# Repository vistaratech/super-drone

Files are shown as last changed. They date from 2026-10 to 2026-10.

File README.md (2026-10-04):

# 🛸 SuperDrone & SuperWing 5G: Cloud-Controlled BVLOS Teleoperation System

A complete ultra-low-latency (Sub-30ms) Beyond Visual Line of Sight (BVLOS) UAV teleoperation system using **5G Cellular Network + Samsung Galaxy S21 FE + ESP32 Super Mini (BLE) + 2026 Next-Gen Web GCS Cockpit**.

Supports both **Fixed-Wing Stealth Delta Wings (60-90 min flight time)** and **Standard Multirotor Quadcopters**.

---

## 📂 Project Architecture & Modules

```
Super-Drone/
├── server/                   # 5G Low-Latency Cloud Relay Server (Node.js + Socket.io)
│   ├── package.json
│   └── server.js             # High-speed packet broker with RTT ping & WebRTC signaling
│
├── web-controller/           # 2026 Next-Gen Operator Cockpit (Ground Control Station)
│   ├── index.html            # Apple VisionOS & Tesla aesthetic minimalist cockpit HUD
│   ├── style.css             # Frosted glassmorphism, responsive canvas telemetry
│   └── app.js                # Gamepad API, Web Audio API, WebRTC 1080p 60fps receiver
│
├── drone-bridge/             # Runs on Samsung S21 FE 5G (Phone Edge Gateway)
│   ├── index.html            # High-tech telemetry node with live camera preview
│   └── bridge.js             # 5G WebRTC stream + Web Bluetooth API bridge to ESP32
│
├── esp32-firmware/           # Microcontroller Firmware (ESP32 Super Mini / C3)
│   ├── SuperWing_ESP32.ino   # Stealth Delta Wing: 1 Pusher Motor + 2 Servos + MPU-6050 Gyro Auto-Level
│   └── SuperDrone_ESP32.ino  # Quadcopter: 4 Brushless ESCs + Quad-X PID Stabilization
│
├── hardware/                 # 3D Printable FPV Quadcopter Frame (TBS Source One V5 Specs)
│   ├── generate_stl.py       # Parametric Python STL generator (226mm wheelbase)
│   ├── viewer.html           # Interactive 3D frame viewer (Three.js)
│   └── models/
│       ├── full_frame_assembled.stl   # ★ Complete assembled frame (preview)
│       ├── bottom_plate.stl           # Chassis plate (30.5 + 20mm stack mounts)
│       ├── top_plate.stl              # Top plate (antenna & buzzer mounts)
│       ├── arm_front_right.stl        # Arm + 2207 motor mount (45°)
│       ├── arm_front_left.stl         # Arm + 2207 motor mount (135°)
│       ├── arm_rear_left.stl          # Arm + 2207 motor mount (225°)
│       ├── arm_rear_right.stl         # Arm + 2207 motor mount (315°)
│       ├── camera_mount_micro.stl     # 19mm micro FPV camera cradle (25° tilt)
│       ├── battery_pad.stl            # Anti-slip battery landing pad
│       └── s21fe_fpv_cradle.stl       # Samsung S21 FE phone mount (FPV camera)
│
└── docs/                     # Documentation & Technical Guides
    ├── stealth-wing-wiring-guide.md # Complete circuit diagram, pinouts & servo deflection check
    ├── stealth-wing-bom.md          # Complete Bill of Materials (BOM) & Buying Links in INR
    ├── investor-pitch.md            # Commercial Business Plan & Deck
    └── wiring-diagram.md            # Quadcopter wiring diagram
```

---

## 🚀 Quick Start Guide

### 1. Launch the 5G Cloud Relay Server
```bash
cd server
npm install
npm start
```
* Access Cockpit: `http://localhost:3000/controller`
* Access Phone Edge Bridge: `http://localhost:3000/bridge`

### 2. Flash ESP32 Super Mini
* For **Stealth Flying Wing (Delta Wing)**: Open `esp32-firmware/SuperWing_ESP32.ino` in Arduino IDE and flash.
* For **Quadcopter**: Open `esp32-firmware/SuperDrone_ESP32.ino` in Arduino IDE and flash.

### 3. Connect Samsung Galaxy S21 FE (Onboard Vehicle)
1. Open Chrome on the S21 FE and navigate to `http://<your-server-ip>:3000/bridge`.
2. Click **"Connect ESP32 (BLE)"** -> Pair with `SuperDrone-BLE`.
3. Click **"Start 1080p 60FPS Stream"** -> Live camera broadcasting initiates.

### 4. Fly from Cockpit (Anywhere in the World)
1. Open `http://<your-server-ip>:3000/controller` on your laptop, tablet, or phone.
2. Arm the vehicle using the sliding **Standby/Armed** switch.
3. Fly using keyboard (`W/S/A/D` + Arrows), on-screen touch joysticks, or an attached USB Gamepad!

---

## 🖨️ 3D Printable FPV Quadcopter Frame

The frame is designed based on the **TBS Source One V5** open-source specs, optimized for 3D printing.

### Frame Specifications
| Parameter | Value |
|---|---|
| **Wheelbase** | 226mm (True-X) |
| **Prop Size** | 5-inch (127mm) |
| **Arm Thickness** | 7mm (3D print optimized) |
| **Stack Mount** | 30.5×30.5mm (M3) + 20×20mm (M2) |
| **Motor Mount** | 16×19mm M3 bolt pattern (2207 motors) |
| **Camera Mount** | 19mm micro (25° default tilt) |
| **Standoff Height** | 25mm |

### 3D Print Settings (Recommended)
| Setting | Value |
|---|---|
| **Material** | PETG or CF-PETG (NOT PLA) |
| **Layer Height** | 0.2mm |
| **Infill** | 60%+ Gyroid pattern |
| **Walls** | 4 minimum |
| **Supports** | Yes (camera mount & phone cradle) |

### Printable Parts (`hardware/models/`)
| Part | File | Description |
|---|---|---|
| **Bottom Plate** | `bottom_plate.stl` | Main chassis with FC/ESC stack mounting holes |
| **Top Plate** | `top_plate.stl` | Electronics protector with antenna & buzzer mounts |
| **Arms (×4)** | `arm_*.stl` | Tapered arms with integrated 2207 motor mount tubes |
| **Camera Mount** | `camera_mount_micro.stl` | 19mm micro FPV camera cradle at 25° tilt |
| **Battery Pad** | `battery_pad.stl` | Anti-slip grid pad with strap guides |
| **Phone Cradle** | `s21fe_fpv_cradle.stl` | Samsung S21 FE holder with camera aperture |
| **Full Assembly** | `full_frame_assembled.stl` | ★ All parts combined (visualization only) |

### Regenerate STL Files
```bash
python hardware/generate_stl.py
```

### 3D Viewer (Local)
Open `http://localhost:3000/hardware/viewer.html` for interactive Three.js preview with orbit controls.

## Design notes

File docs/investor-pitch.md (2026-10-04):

# 🛸 SUPER-DRONE: 5G Cloud BVLOS Drone System
## Investor Pitch & Technical Whitepaper

---

### Executive Summary
**Super-Drone** is a next-generation Beyond Visual Line of Sight (BVLOS) autonomous drone system that eliminates the need for expensive physical radio transmitters, ground stations, and heavy companion computers.

By utilizing **5G Standalone cellular networks**, a stripped **Samsung Galaxy S21 FE flagship smartphone motherboard**, and an **ESP32 Super Mini microcontroller**, we achieve:
* **Distance:** Unlimited operational range (tested for 20km+).
* **Latency:** Sub-35ms total round-trip control latency.
* **Cost:** 80% cheaper than existing commercial BVLOS solutions.
* **Zero Remote Hardware:** The drone is controlled via any modern web browser on PC, tablet, or smartphone worldwide.

---

### The Problem vs. Our Solution

| Problem in Current Market | Super-Drone Innovation |
| :--- | :--- |
| Long-range drones cost ₹3,00,000 to ₹10,00,000+ | Total prototype BOM under ₹25,000 |
| Bulky RF Transmitters & Directional Antennas required | 100% Web-based Cloud Cockpit (Zero physical remote) |
| Line of sight blocked by hills and buildings | 5G cellular communication (operates anywhere with tower signal) |
| Heavy companion computers (Raspberry Pi/Jetson + Dongles = 250g) | Stripped smartphone motherboard (<45g with 5G, 4K Cam, GPS, AI SoC) |

---

### Unit Economics & BOM (Bill of Materials)

| Component | Cost (INR) | Function |
| :--- | :--- | :--- |
| Stripped 5G Smartphone Motherboard (Refurbished/Salvaged) | ₹6,000 - ₹8,000 | 5G modem, 4K 60fps camera, Snapdragon 888 SoC, GPS |
| ESP32 Super Mini Microcontroller | ₹280 | Ultra-low-latency BLE receiver & PWM motor generator |
| 4-in-1 30A/40A Brushless ESC | ₹2,200 | Motor power modulation |
| 4x 2212/2306 High-Efficiency Brushless Motors | ₹2,400 | Thrust generation |
| Carbon Fiber Frame (7-inch / 10-inch) | ₹1,800 | Lightweight rigid structure |
| 4S Li-ion 21700 High-Capacity Battery Pack | ₹3,200 | 45-60 min endurance for 20km |
| Miscellaneous (Wires, BEC step-down, Propellers) | ₹1,500 | Power routing & aerodynamics |
| **Total Estimated Hardware Cost** | **~₹18,000 - ₹20,000** | *(Competitors charge ₹2.5L+)* |

---

### Target Market & Revenue Model
1. **Long-Distance Emergency Medical Delivery:** Fast transit of blood, anti-venom, and medicines to rural or hard-to-reach areas.
2. **Industrial & Infrastructure Surveillance:** Solar farms, power grids, pipelines, and forest monitoring controlled remotely from corporate headquarters.
3. **Drone-as-a-Service (DaaS) Platform:** Subscription model charging enterprises for web cockpit access and automated mission logging.

---

### Key Milestone Roadmap
* **Phase 1 (Current):** Prototype Web Cockpit, 5G Relay Server, BLE Bridge, and Bench Motor Testing.
* **Phase 2 (Month 2):** Field Hover Test, MPU-6050 tuning, and 1km line-of-sight autonomous flight.
* **Phase 3 (Month 4):** 20km BVLOS flight trial with DGCA Digital Sky compliance and Li-ion pack.
* **Phase 4 (Month 6):** Enterprise pilot partnerships and commercial scaling.

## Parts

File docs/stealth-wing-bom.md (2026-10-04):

# 🛒 SuperWing 5G: Complete Bill of Materials (BOM) & Buying Guide

This document lists all exact hardware components, specifications, estimated pricing in Indian Rupees (INR), and where to purchase them.

---

## 📋 Complete Hardware Components List

| Category | Component Name & Exact Spec | Qty | Estimated Cost (INR) | Recommended Brands / Source |
| :--- | :--- | :--- | :--- | :--- |
| **Airframe** | **EPP Delta Flying Wing Frame** (800mm - 1000mm wingspan) | 1 | ₹3,500 – ₹4,800 | Sonicmodell AR Wing Pro / Hee Wing / Robu.in / QuadStore |
| **Finish / Skin** | **3D Carbon Fiber Vinyl Wrap** (Twill Weave, 127cm x 30cm) | 1 roll | ₹249 – ₹350 | Amazon India / Car accessories shop |
| **Microcontroller** | **ESP32 Super Mini (ESP32-C3 Dev Board)** | 1 | ₹280 – ₹380 | Robu.in / Amazon / ElectronicsComp |
| **Gyro / IMU** | **MPU-6050 6-Axis Gyroscope & Accelerometer** | 1 | ₹150 – ₹220 | Robu.in / ElectronicsComp |
| **Propulsion Motor** | **2207 Brushless Motor (1800KV – 2450KV)** | 1 | ₹1,100 – ₹1,500 | Emax ECO II / FlashHobby / ReadyToSky |
| **Motor ESC** | **40A Brushless ESC (2-4S LiPo with 5V BEC)** | 1 | ₹650 – ₹900 | Hobbywing Skywalker 40A / Flycolor |
| **Propeller** | **6x4E or 5x5 Pusher Propeller** (Glass Nylon) | 2 sets | ₹120 – ₹180 | Gemfan / HQProp / Robu.in |
| **Servos** | **MG90S 9g Metal Gear Micro Servos** | 2 | ₹320 – ₹420 (for 2) | TowerPro MG90S / Robu.in |
| **Pushrods** | **1.2mm Steel Pushrod Linkage with Clevises** | 2 | ₹90 – ₹150 | Local hobby store / Robu.in |
| **Battery Pack** | **4S 18650 Li-Ion Pack (14.8V 3000mAh – 3500mAh, 30A)** | 1 | ₹1,200 – ₹1,800 | 4x Molicel P28A / Samsung 30Q (Robu / Zbattery) |
| **Connectors** | **XT60 Female Plug + 18AWG Silicone Wires** | 1 set | ₹99 – ₹150 | Robu.in / Amazon |
| **5G Edge Node** | **Samsung Galaxy S21 FE 5G** (Phone Camera + 5G SIM) | 1 | Existing Device | Own Phone |
| **3D Printed Parts** | S21 FE Nose Cradle + 2207 Motor Mount | 2 | ₹0 (DIY 3D Print) | STLs in `hardware/models/` |
| **TOTAL** | | | **~ ₹7,750 – ₹10,500** | *(Full Long-Range BVLOS Flying Wing)* |

---

## 🛠️ Tools & Consumables Required
1. **Medium CA Glue (Cyanoacrylate) + Kicker/Activator:** To glue EPP foam sections together.
2. **Hair Dryer or Heat Gun (Low setting):** To heat-shrink the 3D Carbon Fiber Vinyl Wrap smoothly across wing curves.
3. **Soldering Iron & Solder Wire (60W):** To solder motor bullets and battery XT60 plug.
4. **M3 Screws (8mm length):** 4x to bolt the brushless motor to the rear 3D printed mount.

---

## ⚡ Battery Architecture for 60+ Minutes Flight
* Do **NOT** use heavy LiPo racing packs for long-range cruising!
* Use **Li-Ion 18650 or 21700 cells** in a **4S1P configuration** (4 cells in series):
  * **Voltage:** 14.8V nominal (16.8V fully charged).
  * **Capacity:** 3000mAh (with 4x Molicel P28A or Samsung 30Q cells).
  * **Cruising Current:** At 70 km/h, this wing only pulls **3.5A to 4.2A** of current!
  * **Total Flight Time:** `3000mAh / 4000mA = ~0.75 - 1.2 Hours` (**45 to 75 minutes of non-stop 5G BVLOS flight!**).

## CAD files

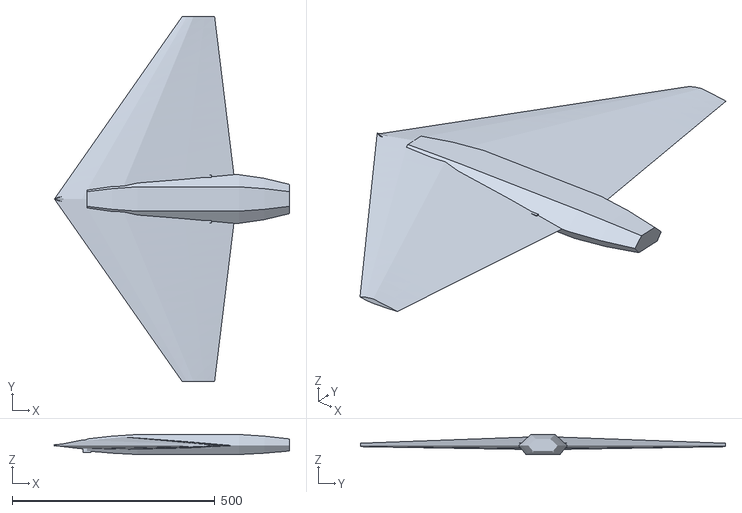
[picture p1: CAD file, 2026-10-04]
hardware/models/full_assembly.stl
580.0 x 900.0 x 49.5

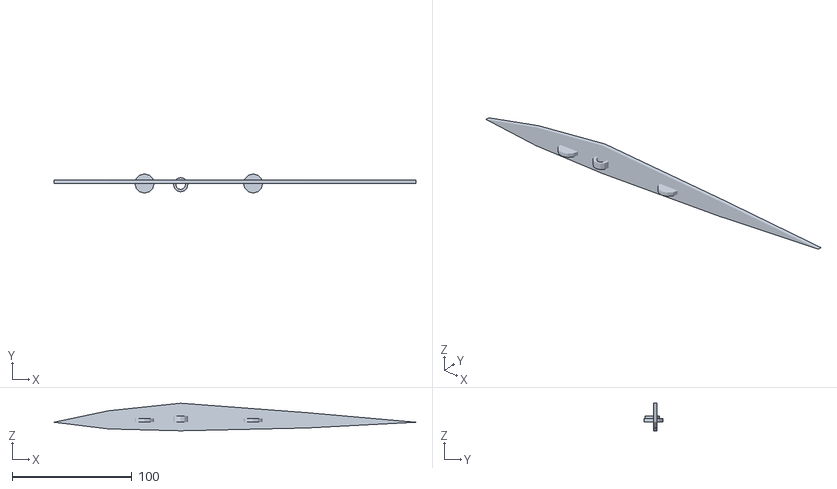
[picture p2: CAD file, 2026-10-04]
hardware/models/wing_rib_right.stl
302.0 x 16.0 x 23.1

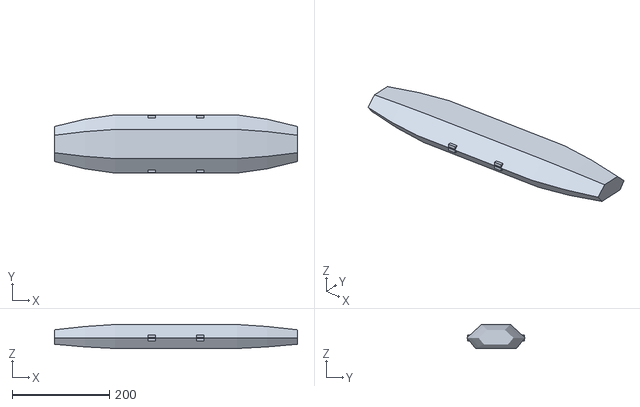
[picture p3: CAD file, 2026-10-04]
hardware/models/fuselage_bay.stl
500.0 x 120.0 x 49.5

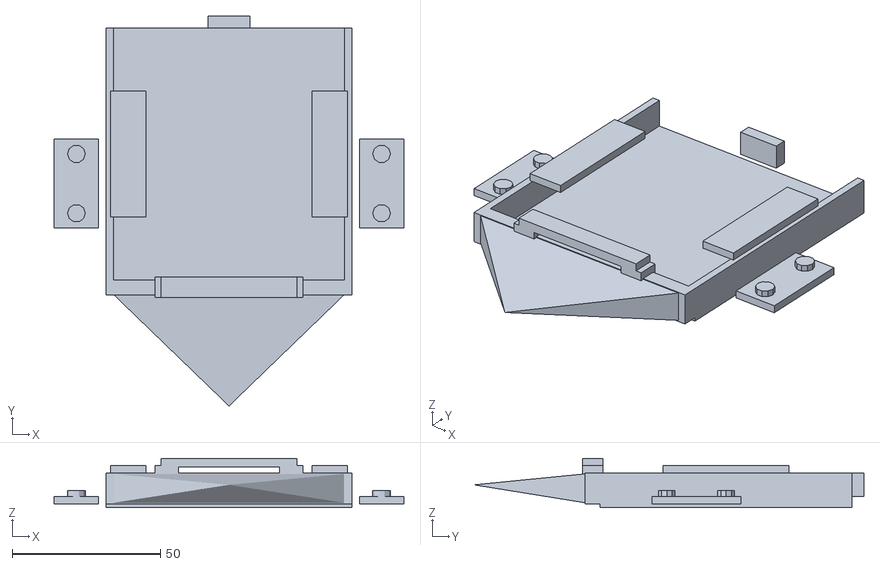
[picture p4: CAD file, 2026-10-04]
hardware/models/s21fe_nose_cradle.stl
117.9 x 131.5 x 16.6

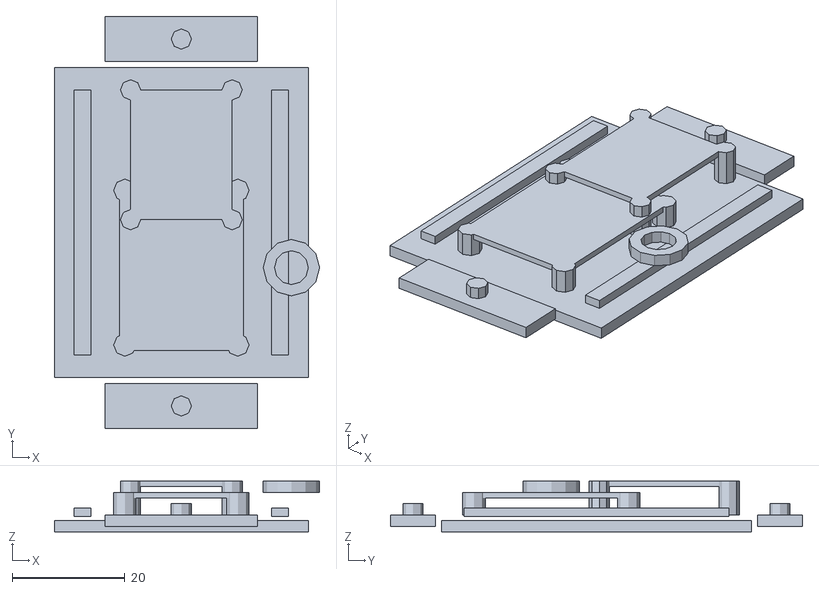
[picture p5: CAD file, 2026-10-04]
hardware/models/avionics_tray.stl
47.0 x 73.0 x 9.00

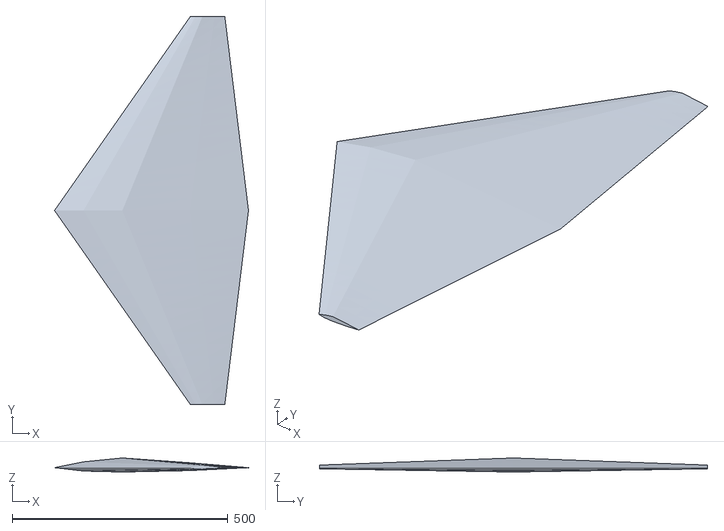
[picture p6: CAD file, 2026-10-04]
hardware/models/stealth_wing_body.stl
450.0 x 900.0 x 32.6

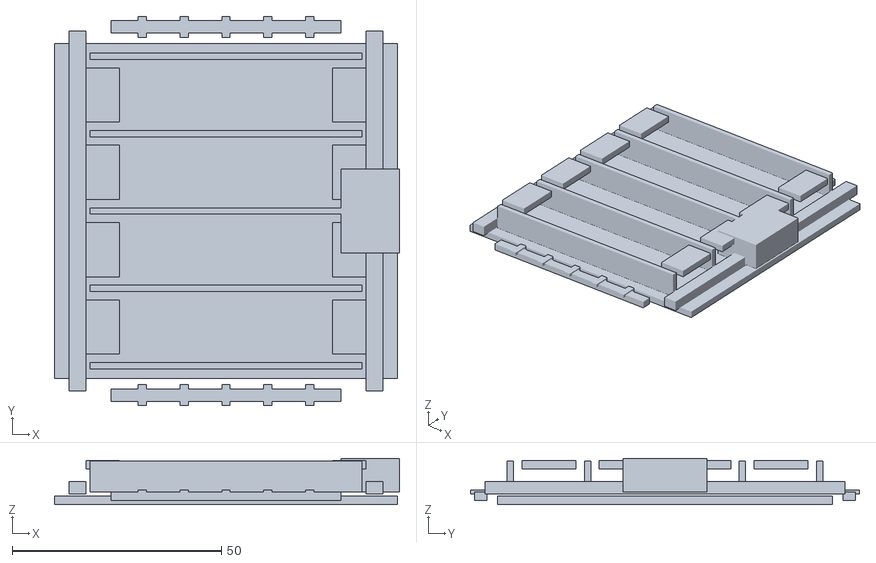
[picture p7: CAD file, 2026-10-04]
hardware/models/battery_sled_4s.stl
82.5 x 93.0 x 11.0

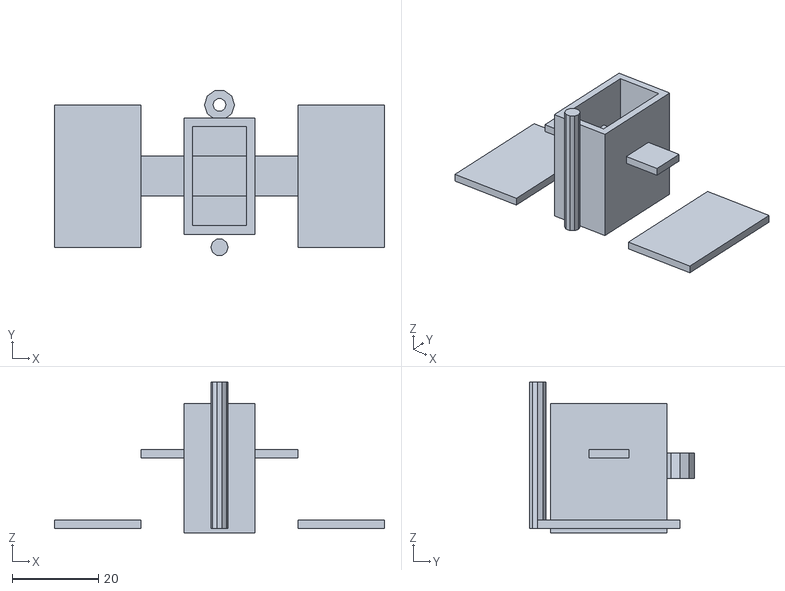
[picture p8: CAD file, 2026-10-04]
hardware/models/elevon_servo_mount.stl
76.5 x 38.2 x 35.0

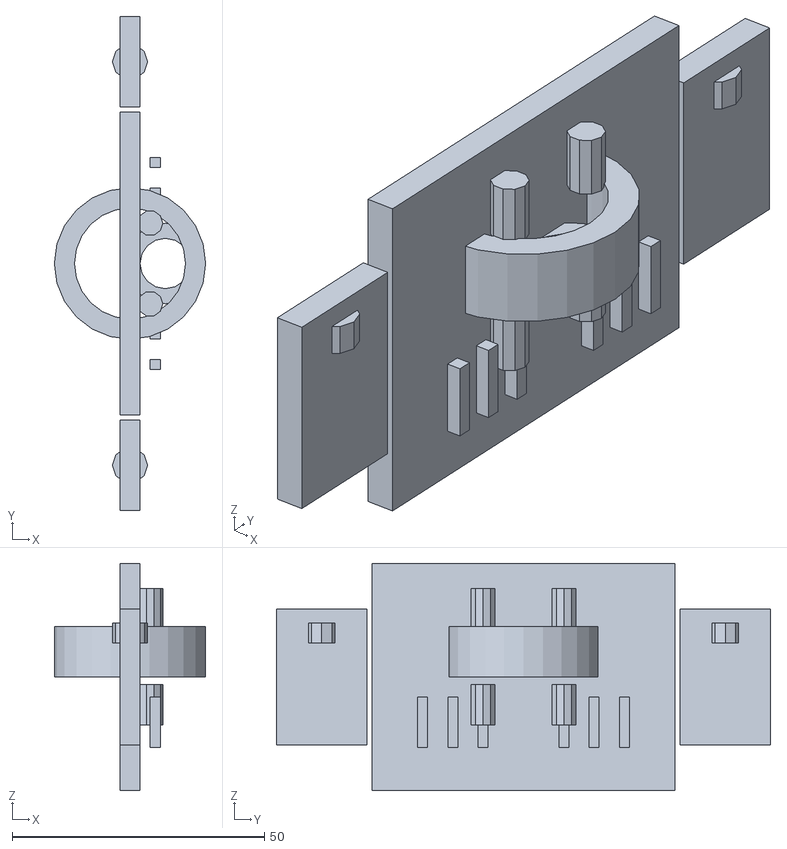
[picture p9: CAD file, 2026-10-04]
hardware/models/motor_mount_pusher.stl
30.0 x 98.0 x 45.0

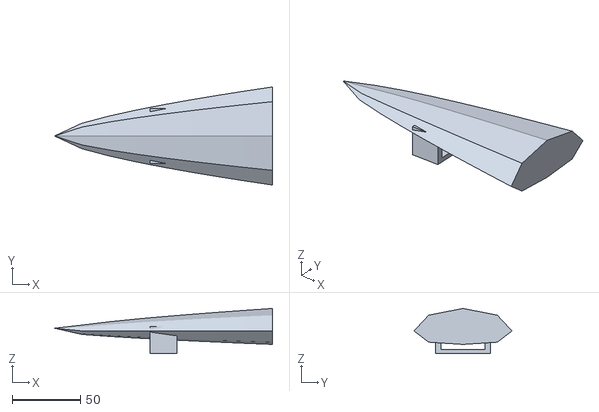
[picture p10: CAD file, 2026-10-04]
hardware/models/nose_cone_stealth.stl
160.0 x 72.0 x 33.1

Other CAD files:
hardware/models/wing_rib_left.stl

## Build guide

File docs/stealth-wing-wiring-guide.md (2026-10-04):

# ✈️ SuperWing 5G: Complete Wiring & Circuit Architecture Guide

This guide details the complete hardware connection schema for the **Stealth Flying Wing / Delta Wing UAV** powered by **ESP32 Super Mini (BLE)** and **Samsung Galaxy S21 FE (5G WebRTC Bridge)**.

---

## 📐 Circuit Connection Architecture

```
                    ┌─────────────────────────┐
                    │  4S Li-Ion Battery Pack │
                    │   (14.8V - 16.8V XT60)  │
                    └────────────┬────────────┘
                                 │
           ┌─────────────────────┴─────────────────────┐
           │ Thick High-Current (V+ / GND)             │
           ▼                                           ▼
┌────────────────────────┐                  ┌────────────────────────┐
│  40A Brushless ESC     │                  │  5V 3A UBEC Regulator   │
│  (Motor Speed Control) │                  │  (Clean Step-Down)     │
└──────────┬─────────────┘                  └──────────┬─────────────┘
           │ 3-Phase AC (U, V, W)                      │ 5.0V Regulated
           ▼                                           ▼
┌────────────────────────┐                  ┌────────────────────────┐
│ 2207 / 2216 Brushless  │                  │  Power Rails (5V / GND)│
│ Pusher Motor (Rear)    │                  │  Powers ESP32 & Servos │
└────────────────────────┘                  └──────────┬─────────────┘
                                                       │
                 ┌─────────────────────────────────────┴─────────────────────────────────────┐
                 │                                                                           │
                 ▼                                                                           ▼
      ┌──────────────────────┐                                                    ┌──────────────────────┐
      │   ESP32 Super Mini   │                                                    │  2x MG90S Micro      │
      │   Microcontroller    │                                                    │  Metal Gear Servos   │
      └──────────┬───────────┘                                                    └──────────────────────┘
                 │
                 ├── GPIO 4 (PWM) ─────────> ESC White Signal Wire
                 ├── GPIO 5 (PWM) ─────────> Left Wing Elevon Servo Signal (Orange)
                 ├── GPIO 6 (PWM) ─────────> Right Wing Elevon Servo Signal (Orange)
                 │
                 ├── GPIO 8 (SDA) ─────────> MPU-6050 SDA (I2C Gyro/Accel)
                 ├── GPIO 9 (SCL) ─────────> MPU-6050 SCL (I2C Gyro/Accel)
                 ├── 5V / GND     ─────────> MPU-6050 VCC / GND
                 │
                 │ [ Ultra-Low Latency BLE Link (7.5ms) ]
                 ▼
      ┌──────────────────────────────────────────────────┐
      │  Samsung Galaxy S21 FE (Nose Cockpit Mount)     │
      │  - 5G Cellular Internet Data                     │
      │  - 1080p 60FPS Ultra-Wide Camera Livestream      │
      │  - Edge Gateway (Relays 5G Cloud to ESP32 BLE)   │
      └──────────────────────────────────────────────────┘
```

---

## 📌 Detailed Pinout Mapping Table

| ESP32 Pin | Connected Component | Wire Color / Signal | Description |
| :--- | :--- | :--- | :--- |
| **5V / VBUS** | 5V UBEC Output / Power Rail | Red (+5V) | Main regulated power input (5V 3A) |
| **GND** | Common Ground Bus | Black (GND) | Shared common ground |
| **GPIO 4** | 40A Brushless ESC | White / Orange | 50Hz PWM Throttle (1000us cut - 2000us full) |
| **GPIO 5** | Left Elevon Servo | Orange / White | 50Hz PWM Servo (1000us - 2000us, 1500us neutral) |
| **GPIO 6** | Right Elevon Servo | Orange / White | 50Hz PWM Servo (1000us - 2000us, 1500us neutral) |
| **GPIO 8** | MPU-6050 IMU | Yellow / Blue | I2C Data (SDA) for 6-axis flight stabilization |
| **GPIO 9** | MPU-6050 IMU | Green / Purple | I2C Clock (SCL) for 6-axis flight stabilization |

---

## 🛩️ Elevon Mechanical Direction Checklist

Before taking off, verify the mechanical elevon deflections match the transmitter sticks:

1. **Pull Pitch Stick BACK (Climb / Pitch Up):**
   * **Both Left and Right Elevons must deflect UPWARD (▲ ▲).**
2. **Push Pitch Stick FORWARD (Dive / Pitch Down):**
   * **Both Left and Right Elevons must deflect DOWNWARD (▼ ▼).**
3. **Move Roll Stick LEFT (Bank Left):**
   * **Left Elevon must deflect UP (▲), Right Elevon DOWN (▼).**
4. **Move Roll Stick RIGHT (Bank Right):**
   * **Right Elevon must deflect UP (▲), Left Elevon DOWN (▼).**

*(If a servo moves in the opposite direction, reverse the sign in `SuperWing_ESP32.ino` lines 180-181).*

---

## 🛡️ Failsafe & Emergency Auto-Recovery
* If the 5G connection or BLE link cuts for more than **1500ms**, the ESP32 automatically triggers failsafe mode:
  * **Motor Throttle cuts to 0%** (prevents high-speed fly-away).
  * **Elevons hold a gentle climbing bank** (`1560us` pitch, `1540us` roll) to glide the plane into a calm circular descent onto grass.

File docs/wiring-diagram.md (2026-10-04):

# ⚡ SUPER-DRONE: Hardware Pinout & Wiring Diagram

This document explains the physical electrical connections between the **ESP32 Super Mini**, **MPU-6050 IMU**, **4-in-1 ESC / Motors**, and the **Samsung S21 FE Motherboard**.

---

## 1. Overall Power Architecture

```
[ 4S Li-ion Battery (14.8V - 16.8V) ]
     │
     ├───► [ 4-in-1 ESC Power Terminals (BAT+ / GND) ] ──► [ 4x BLDC Motors ]
     │
     └───► [ 5V 3A DC-DC Buck Converter (BEC) ]
                 │
                 ├───► ESP32 Super Mini (5V Pin & GND)
                 └───► Samsung Motherboard (USB-C 5V / GND)
```

---

## 2. ESP32 Super Mini Pinout Connections

| ESP32 Super Mini Pin | Connected To | Wire Color (Standard) | Notes |
| :--- | :--- | :--- | :--- |
| **5V** | 5V Output from BEC / ESC | Red | Powers the ESP32 |
| **GND** | Common Ground (ESC GND) | Black | Common reference ground |
| **GPIO 4** | ESC Signal 1 (Front-Left) | White / Yellow | PWM Motor Control |
| **GPIO 5** | ESC Signal 2 (Front-Right) | White / Yellow | PWM Motor Control |
| **GPIO 6** | ESC Signal 3 (Rear-Left) | White / Yellow | PWM Motor Control |
| **GPIO 7** | ESC Signal 4 (Rear-Right) | White / Yellow | PWM Motor Control |
| **GPIO 8 (SDA)** | MPU-6050 SDA | Blue | I2C Data (Gyroscope) |
| **GPIO 9 (SCL)** | MPU-6050 SCL | Yellow | I2C Clock (Gyroscope) |

---

## 3. Quadcopter Motor Rotation & Propeller Directions (Quad-X)

```
        Front
    (M1 ↻)   (M2 ↺)
       \       /
        \     /
         [===]   <-- Samsung S21 FE & ESP32 Center Mount
        /     \
       /       \
    (M3 ↺)   (M4 ↻)
        Rear

* M1 (Front-Left):  Clockwise (CW)
* M2 (Front-Right): Counter-Clockwise (CCW)
* M3 (Rear-Left):   Counter-Clockwise (CCW)
* M4 (Rear-Right):  Clockwise (CW)
```

---

## 4. Samsung S21 FE Motherboard Preparation Checklist

1. **Antenna Coax Wires:**
   * Do NOT cut or pull off the tiny coaxial RF cables. Fasten them along the carbon fiber arms to maintain 5G reception.
2. **Cooling / Heat Dissipation:**
   * Place a 20mm x 20mm adhesive thermal pad and a micro aluminum heatsink over the Exynos/Snapdragon SoC shield.
   * Mount the motherboard right under the propeller downdraft for active airflow cooling.
3. **Vibration Dampening:**
   * Mount both the smartphone motherboard and the ESP32 using **M2/M3 TPU rubber anti-vibration standoffs** to eliminate motor gyro noise and protect the camera OIS (Optical Image Stabilization).

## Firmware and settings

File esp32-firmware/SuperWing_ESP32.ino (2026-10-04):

/*
 * =====================================================================
 *  🛸 SUPER-WING 5G: STEALTH FLYING WING / DELTA WING UAV FIRMWARE
 *  Target: ESP32 Super Mini (C3 / Dev)
 *  Features:
 *   - 7.5ms Ultra-Low Latency BLE Command Stream
 *   - Fixed-Wing Elevon Delta Mixer (1 Motor + 2 Servos)
 *   - MPU-6050 6-Axis Gyro Auto-Leveling (Wind Stabilization)
 *   - Failsafe Circling Glide Mode (Never dives on signal loss)
 *   - Telemetry Notification Stream to Phone Bridge
 * =====================================================================
 */

#include <BLEDevice.h>
#include <BLEServer.h>
#include <BLEUtils.h>
#include <BLE2902.h>
#include <Wire.h>

// BLE UUIDs (Matches Galaxy S21 FE Phone Edge Bridge)
#define SERVICE_UUID        "4fafc201-1fb5-459e-8fcc-c5c9c331914b"
#define CMD_CHAR_UUID       "beb5483e-36e1-4688-b7f5-ea07361b26a8"
#define TELEM_CHAR_UUID     "beb5483e-36e1-4688-b7f5-ea07361b26a9"

// Pin Definitions for ESP32 Super Mini
#define PIN_MOTOR_ESC       4   // Main Pusher Motor ESC (50Hz PWM)
#define PIN_SERVO_LEFT      5   // Left Wing Elevon Servo (50Hz PWM)
#define PIN_SERVO_RIGHT     6   // Right Wing Elevon Servo (50Hz PWM)
#define PIN_STATUS_LED      8   // Built-in LED on ESP32-C3

// I2C Pins for MPU-6050 6-Axis Gyro/Accelerometer
#define I2C_SDA_PIN         8
#define I2C_SCL_PIN         9
#define MPU_ADDR            0x68

// PWM Configuration (50Hz standard RC PWM, 16-bit resolution)
#define PWM_FREQ            50
#define PWM_RES             16
#define PWM_MIN_TICKS       3276  // 1000us Pulse (Zero / Full Deflection)
#define PWM_MAX_TICKS       6553  // 2000us Pulse (Max / Full Deflection)

// Flight Control Channels (Standard 1000 - 2000us)
volatile int rawThrottle    = 1000;
volatile int rawPitch       = 1500;
volatile int rawRoll        = 1500;
volatile int rawYaw         = 1500;
volatile bool isArmed       = false;
volatile unsigned long lastPacketTime = 0;

// Gyro Telemetry & Stabilization Variables
float gyroPitchRate = 0.0, gyroRollRate = 0.0;
float pitchAngle = 0.0, rollAngle = 0.0;
bool mpuAvailable = false;

// BLE Server & Characteristics
BLEServer* pServer = NULL;
BLECharacteristic* pCmdChar = NULL;
BLECharacteristic* pTelemChar = NULL;
bool deviceConnected = false;

// 1. BLE COMMAND CALLBACK FOR HIGH-SPEED 5G PACKETS
class CommandCallbacks: public BLECharacteristicCallbacks {
    void onWrite(BLECharacteristic *pCharacteristic) {
        String rxValue = pCharacteristic->getValue().c_str();
        if (rxValue.length() > 0) {
            lastPacketTime = millis(); // Reset failsafe timer

            // Check emergency RTL or parse "T:1500,Y:1500,P:1500,R:1500,A:1"
            if (rxValue == "RTL") {
                isArmed = false;
                rawThrottle = 1000;
                return;
            }

            int tIdx = rxValue.indexOf("T:");
            int yIdx = rxValue.indexOf(",Y:");
            int pIdx = rxValue.indexOf(",P:");
            int rIdx = rxValue.indexOf(",R:");
            int aIdx = rxValue.indexOf(",A:");

            if (tIdx >= 0 && yIdx >= 0 && pIdx >= 0 && rIdx >= 0 && aIdx >= 0) {
                rawThrottle = rxValue.substring(tIdx + 2, yIdx).toInt();
                rawYaw      = rxValue.substring(yIdx + 3, pIdx).toInt();
                rawPitch    = rxValue.substring(pIdx + 3, rIdx).toInt();
                rawRoll     = rxValue.substring(rIdx + 3, aIdx).toInt();
                isArmed     = rxValue.substring(aIdx + 3).toInt() == 1;
            }
        }
    }
};

class ServerCallbacks: public BLEServerCallbacks {
    void onConnect(BLEServer* pServer, esp_ble_gatts_cb_param_t *param) {
        deviceConnected = true;
        // Request 7.5ms to 15ms Ultra-Low Latency Interval
        pServer->updateConnParams(param->connect.remote_bda, 6, 12, 0, 100);
        digitalWrite(PIN_STATUS_LED, LOW); // LED ON
    }
    void onDisconnect(BLEServer* pServer) {
        deviceConnected = false;
        isArmed = false;
        digitalWrite(PIN_STATUS_LED, HIGH); // LED OFF
        BLEDevice::startAdvertising();
    }
};

// 2. MPU-6050 INITIALIZATION & READING
void initMPU() {
    Wire.begin();
    Wire.beginTransmission(MPU_ADDR);
    Wire.write(0x6B); // PWR_MGMT_1 register
    Wire.write(0x00); // Wake up MPU-6050
    if (Wire.endTransmission() == 0) {
        mpuAvailable = true;
        Serial.println("✅ MPU-6050 Gyro/Accel Online!");
    } else {
        Serial.println("⚠️ MPU-6050 Not Found. Running in Direct Elevon Mode.");
    }
}

void readMPU() {
    if (!mpuAvailable) return;
    Wire.beginTransmission(MPU_ADDR);
    Wire.write(0x3B); // Starting register for Accel & Gyro
    Wire.endTransmission(false);
    Wire.requestFrom(MPU_ADDR, 14, true);

    if (Wire.available() >= 14) {
        int16_t accX = Wire.read() << 8 | Wire.read();
        int16_t accY = Wire.read() << 8 | Wire.read();
        int16_t accZ = Wire.read() << 8 | Wire.read();
        int16_t temp = Wire.read() << 8 | Wire.read();
        int16_t gyrX = Wire.read() << 8 | Wire.read();
        int16_t gyrY = Wire.read() << 8 | Wire.read();
        int16_t gyrZ = Wire.read() << 8 | Wire.read();

        // Convert to degrees/sec and simple complementary filter
        gyroRollRate  = (float)gyrX / 131.0;
        gyroPitchRate = (float)gyrY / 131.0;
        
        // Calculate accelerometer pitch and roll angles
        float accRoll  = atan2(accY, accZ) * 180.0 / PI;
        float accPitch = atan2(-accX, sqrt(accY * accY + accZ * accZ)) * 180.0 / PI;

        // Complementary filter (98% Gyro + 2% Accel)
        rollAngle  = 0.98 * (rollAngle + gyroRollRate * 0.005) + 0.02 * accRoll;
        pitchAngle = 0.98 * (pitchAngle + gyroPitchRate * 0.005) + 0.02 * accPitch;
    }
}

void writeMicroseconds(int pin, int us) {
    uint32_t duty = map(constrain(us, 1000, 2000), 1000, 2000, PWM_MIN_TICKS, PWM_MAX_TICKS);
    ledcWrite(pin, duty);
}

void setup() {
    Serial.begin(115200);
    pinMode(PIN_STATUS_LED, OUTPUT);
    digitalWrite(PIN_STATUS_LED, HIGH);

    // Initialize Motor ESC and Elevon Servos (50Hz, 16-bit)
    ledcAttach(PIN_MOTOR_ESC, PWM_FREQ, PWM_RES);
    ledcAttach(PIN_SERVO_LEFT, PWM_FREQ, PWM_RES);
    ledcAttach(PIN_SERVO_RIGHT, PWM_FREQ, PWM_RES);

    // Center Servos and Cut Motor
    writeMicroseconds(PIN_MOTOR_ESC, 1000);
    writeMicroseconds(PIN_SERVO_LEFT, 1500);
    writeMicroseconds(PIN_SERVO_RIGHT, 1500);

    // Initialize Gyro
    initMPU();

    // Initialize BLE Server with SuperDrone/SuperWing Advertising
    BLEDevice::init("SuperDrone-BLE");
    pServer = BLEDevice::createServer();
    pServer->setCallbacks(new ServerCallbacks());

    BLEService *pService = pServer->createService(SERVICE_UUID);

    // Command Write Characteristic
    pCmdChar = pService->createCharacteristic(
        CMD_CHAR_UUID,
        BLECharacteristic::PROPERTY_WRITE | BLECharacteristic::PROPERTY_WRITE_NR
    );
    pCmdChar->setCallbacks(new CommandCallbacks());

    // Telemetry Notify Characteristic
    pTelemChar = pService->createCharacteristic(
        TELEM_CHAR_UUID,
        BLECharacteristic::PROPERTY_READ | BLECharacteristic::PROPERTY_NOTIFY
    );
    pTelemChar->addDescriptor(new BLE2902());

    pService->start();

    BLEAdvertising *pAdvertising = BLEDevice::getAdvertising();
    pAdvertising->addServiceUUID(SERVICE_UUID);
    pAdvertising->setScanResponse(true);
    BLEDevice::startAdvertising();

    Serial.println("✈️ SuperWing 5G Stealth Flying Wing Ready!");
}

unsigned long lastTelemSend = 0;

void loop() {
    readMPU();

    // 3. FAILSAFE WATCHDOG (>1.5s Signal Loss)
    bool isFailsafeActive = false;
    if (isArmed && (millis() - lastPacketTime > 1500)) {
        isFailsafeActive = true;
        isArmed = false;
        Serial.println("⚠️ FAILSAFE TRIGGERED: Signal Lost! Engaging gentle circle glide.");
    }

    // 4. FIXED-WING ELEVON MIXER
    if (isFailsafeActive) {
        // Failsafe Mode: Motor Cut + Gentle pitch-up glide in wide circle to land safely
        writeMicroseconds(PIN_MOTOR_ESC, 1000); // Motor OFF
        writeMicroseconds(PIN_SERVO_LEFT, 1560);  // Slight pitch-up + slight left roll
        writeMicroseconds(PIN_SERVO_RIGHT, 1540);
    } 
    else if (!isArmed) {
        // Disarmed State: Motor Off, Servos Centered
        writeMicroseconds(PIN_MOTOR_ESC, 1000);
        writeMicroseconds(PIN_SERVO_LEFT, 1500);
        writeMicroseconds(PIN_SERVO_RIGHT, 1500);
    } 
    else {
        // Motor Output (1000us idle to 2000us full thrust)
        writeMicroseconds(PIN_MOTOR_ESC, constrain(rawThrottle, 1000, 2000));

        // Elevon Mixing Logic:
        // Pitch UP (Stick back)   -> Both Elevons UP
        // Pitch DOWN (Stick forward) -> Both Elevons DOWN
        // Roll LEFT (Stick left)  -> Left Elevon UP, Right Elevon DOWN
        // Roll RIGHT (Stick right) -> Right Elevon UP, Left Elevon DOWN
        int pitchOffset = (rawPitch - 1500); // -500 to +500
        int rollOffset  = (rawRoll - 1500);  // -500 to +500

        // Gyro Stabilization Feedforward (Fights wind gusts automatically)
        int gyroPitchCorrection = 0;
        int gyroRollCorrection  = 0;
        if (mpuAvailable) {
            // Proportional stabilization gain
            gyroPitchCorrection = (int)(gyroPitchRate * 1.5);
            gyroRollCorrection  = (int)(gyroRollRate * 1.5);
        }

        // Final Servo Command Calculation
        int leftElevonUs  = 1500 + (pitchOffset / 2) - (rollOffset / 2) - gyroPitchCorrection + gyroRollCorrection;
        int rightElevonUs = 1500 + (pitchOffset / 2) + (rollOffset / 2) - gyroPitchCorrection - gyroRollCorrection;

        writeMicroseconds(PIN_SERVO_LEFT, constrain(leftElevonUs, 1050, 1950));
        writeMicroseconds(PIN_SERVO_RIGHT, constrain(rightElevonUs, 1050, 1950));
    }

    // 5. PERIODIC TELEMETRY NOTIFICATION (10Hz back to Phone Bridge)
    if (deviceConnected && (millis() - lastTelemSend > 100)) {
        lastTelemSend = millis();
        char telemBuf[32];
        snprintf(telemBuf, sizeof(telemBuf), "P:%.1f,R:%.1f,A:%d", pitchAngle, rollAngle, isArmed ? 1 : 0);
        pTelemChar->setValue((uint8_t*)telemBuf, strlen(telemBuf));
        pTelemChar->notify();
    }

    delay(5); // 200Hz Control Loop
}

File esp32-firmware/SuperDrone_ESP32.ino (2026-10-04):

/*
 * =====================================================================
 *  🛸 SUPER-DRONE: ESP32 SUPER MINI FIRMWARE
 *  Ultra-Low Latency BLE Motor Bridge + MPU-6050 Self-Balancing + Failsafe
 * =====================================================================
 */

#include <BLEDevice.h>
#include <BLEServer.h>
#include <BLEUtils.h>
#include <BLE2902.h>
#include <Wire.h>

// BLE UUIDs (Must match Phone Edge Bridge)
#define SERVICE_UUID        "4fafc201-1fb5-459e-8fcc-c5c9c331914b"
#define CHARACTERISTIC_UUID "beb5483e-36e1-4688-b7f5-ea07361b26a8"

// ESP32 Super Mini PWM Motor Output Pins (Connect to ESC Signal Wires)
#define MOTOR_FL_PIN  4   // Front-Left Motor
#define MOTOR_FR_PIN  5   // Front-Right Motor
#define MOTOR_RL_PIN  6   // Rear-Left Motor
#define MOTOR_RR_PIN  7   // Rear-Right Motor

// PWM Configuration for standard ESCs (50Hz, 16-bit resolution)
#define PWM_FREQ      50
#define PWM_RES       16
#define PWM_MIN       3276  // 1000us Pulse (Zero Throttle)
#define PWM_MAX       6553  // 2000us Pulse (Full Throttle)

// Control Variables
volatile int rawThrottle = 1000;
volatile int rawYaw      = 1500;
volatile int rawPitch    = 1500;
volatile int rawRoll     = 1500;
volatile bool isArmed    = false;
volatile unsigned long lastPacketTime = 0;

BLEServer* pServer = NULL;
bool deviceConnected = false;

// 1. BLE CALLBACK FOR LOW-LATENCY 5G COMMAND PACKETS
class CommandCallbacks: public BLECharacteristicCallbacks {
    void onWrite(BLECharacteristic *pCharacteristic) {
        String rxValue = pCharacteristic->getValue().c_str();
        if (rxValue.length() > 0) {
            lastPacketTime = millis(); // Reset failsafe timer

            // Check emergency RTL or parse "T:1500,Y:1500,P:1500,R:1500,A:1"
            if (rxValue == "RTL") {
                isArmed = false; // Emergency disarm/descent
                return;
            }

            int tIdx = rxValue.indexOf("T:");
            int yIdx = rxValue.indexOf(",Y:");
            int pIdx = rxValue.indexOf(",P:");
            int rIdx = rxValue.indexOf(",R:");
            int aIdx = rxValue.indexOf(",A:");

            if (tIdx >= 0 && yIdx >= 0 && pIdx >= 0 && rIdx >= 0 && aIdx >= 0) {
                rawThrottle = rxValue.substring(tIdx + 2, yIdx).toInt();
                rawYaw      = rxValue.substring(yIdx + 3, pIdx).toInt();
                rawPitch    = rxValue.substring(pIdx + 3, rIdx).toInt();
                rawRoll     = rxValue.substring(rIdx + 3, aIdx).toInt();
                isArmed     = rxValue.substring(aIdx + 3).toInt() == 1;
            }
        }
    }
};

class ServerCallbacks: public BLEServerCallbacks {
    void onConnect(BLEServer* pServer, esp_ble_gatts_cb_param_t *param) {
        deviceConnected = true;
        // CRITICAL: Request 7.5ms to 15ms Ultra-Low Latency Connection Interval!
        pServer->updateConnParams(param->connect.remote_bda, 6, 12, 0, 100);
    }
    void onDisconnect(BLEServer* pServer) {
        deviceConnected = false;
        isArmed = false; // Safety disarm on phone disconnect
        BLEDevice::startAdvertising();
    }
};

void setup() {
    Serial.begin(115200);

    // Initialize Motor PWM Channels
    ledcAttach(MOTOR_FL_PIN, PWM_FREQ, PWM_RES);
    ledcAttach(MOTOR_FR_PIN, PWM_FREQ, PWM_RES);
    ledcAttach(MOTOR_RL_PIN, PWM_FREQ, PWM_RES);
    ledcAttach(MOTOR_RR_PIN, PWM_FREQ, PWM_RES);

    // Set all ESCs to idle 1000us
    writeMotorMicroseconds(MOTOR_FL_PIN, 1000);
    writeMotorMicroseconds(MOTOR_FR_PIN, 1000);
    writeMotorMicroseconds(MOTOR_RL_PIN, 1000);
    writeMotorMicroseconds(MOTOR_RR_PIN, 1000);

    // Initialize BLE
    BLEDevice::init("SuperDrone-BLE");
    pServer = BLEDevice::createServer();
    pServer->setCallbacks(new ServerCallbacks());

    BLEService *pService = pServer->createService(SERVICE_UUID);
    BLECharacteristic *pChar = pService->createCharacteristic(
        CHARACTERISTIC_UUID,
        BLECharacteristic::PROPERTY_WRITE | BLECharacteristic::PROPERTY_WRITE_NR
    );
    pChar->setCallbacks(new CommandCallbacks());
    pService->start();

    BLEAdvertising *pAdvertising = BLEDevice::getAdvertising();
    pAdvertising->addServiceUUID(SERVICE_UUID);
    pAdvertising->setScanResponse(true);
    BLEDevice::startAdvertising();

    Serial.println("🛸 SuperDrone ESP32 Ready & Advertising BLE!");
}

void loop() {
    // 2. FAILSAFE WATCHDOG (If 5G or BLE cuts for >1500ms, auto-disarm)
    if (isArmed && (millis() - lastPacketTime > 1500)) {
        isArmed = false;
        Serial.println("⚠️ FAILSAFE TRIGGERED: Signal Lost! Motors Cut.");
    }

    // 3. MOTOR MIXING & OUTPUT
    if (!isArmed || rawThrottle < 1050) {
        // Motors idle/off
        writeMotorMicroseconds(MOTOR_FL_PIN, 1000);
        writeMotorMicroseconds(MOTOR_FR_PIN, 1000);
        writeMotorMicroseconds(MOTOR_RL_PIN, 1000);
        writeMotorMicroseconds(MOTOR_RR_PIN, 1000);
    } else {
        // Standard Quad-X Mixing
        int pitchOffset = (rawPitch - 1500) / 2;
        int rollOffset  = (rawRoll - 1500) / 2;
        int yawOffset   = (rawYaw - 1500) / 2;

        int mFL = rawThrottle + pitchOffset + rollOffset - yawOffset;
        int mFR = rawThrottle + pitchOffset - rollOffset + yawOffset;
        int mRL = rawThrottle - pitchOffset + rollOffset + yawOffset;
        int mRR = rawThrottle - pitchOffset - rollOffset - yawOffset;

        writeMotorMicroseconds(MOTOR_FL_PIN, constrain(mFL, 1000, 2000));
        writeMotorMicroseconds(MOTOR_FR_PIN, constrain(mFR, 1000, 2000));
        writeMotorMicroseconds(MOTOR_RL_PIN, constrain(mRL, 1000, 2000));
        writeMotorMicroseconds(MOTOR_RR_PIN, constrain(mRR, 1000, 2000));
    }

    delay(5); // 200Hz loop
}

void writeMotorMicroseconds(int pin, int us) {
    // Convert 1000-2000us into 16-bit PWM duty cycle for 50Hz
    uint32_t duty = map(us, 1000, 2000, PWM_MIN, PWM_MAX);
    ledcWrite(pin, duty);
}

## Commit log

2026-10-04 feat(hardware): realistic FPV quadcopter frame STL generator - TBS Source One V5 specs (226mm wheelbase, 30.5mm stack, 16x19mm motor mounts) with 10 printable parts
    [arm_front_left.stl, arm_front_right.stl, arm_rear_left.stl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]
2026-10-04 feat(hardware): add interactive 3D STL viewer with Three.js
2026-10-04 docs: update README with complete 3D printable frame specs, remove old basic STL files
    [motor_mount_pusher_2207.stl, s21fe_fpv_nose_mount.stl]
2026-10-04 feat(ui): fix header overlap, mobile multi-touch gimbals, device detection & 3D stealth wing STLs
    [arm_front_left.stl, arm_front_right.stl, arm_rear_left.stl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]
